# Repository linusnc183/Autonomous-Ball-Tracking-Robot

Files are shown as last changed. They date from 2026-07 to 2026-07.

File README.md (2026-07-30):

# Autonomous Ball Tracking Robot

A two-wheeled robot that visually tracks and follows a red ball. A Raspberry Pi handles vision (Picamera2 + OpenCV) and sends drive commands over UART to a custom STM32-based motor controller PCB, which closes the loop with encoder feedback and PID.

I designed the controller PCB from scratch in KiCad and wrote the embedded firmware in C (STM32CubeIDE, HAL).

**Skills demonstrated:** PCB design (KiCad) · embedded C / STM32 HAL · real-time control loops (PID) · analog/digital circuit design (power regulation, signal protection) · computer vision (OpenCV) · serial communication protocol design

https://github.com/user-attachments/assets/ed4e9871-f768-4ec5-b8f6-aebbd3194bc8

## Table of Contents

- [Features](#features)
- [System Architecture](#system-architecture)
- [Hardware](#hardware)
  - [Power](#power-powerkicad_sch)
  - [Motor Driver](#motor-driver-motordriverkicad_sch)
  - [Sensors](#sensors-sensorskicad_sch)
  - [MCU](#mcu-stm32kicad_sch)
  - [Raspberry Pi Interface](#raspberry-pi-interface-raspberrypikicad_sch)
  - [Debug](#debug-debugkicad_sch)
- [Firmware](#firmware-stm32-c--hal-stm32cubeide)
- [Vision](#vision-raspberry-pi-python)
- [Repository Structure](#repository-structure)
- [Getting Started](#getting-started)
- [Testing](#testing)
- [Future Improvements](#future-improvements)

## Features

- Real-time red-ball tracking with Picamera2 + OpenCV
- Custom 2-layer STM32G431 motor controller PCB with protection circuitry
- Closed-loop wheel velocity control via quadrature encoders + independent left/right PID
- UART link between Raspberry Pi and STM32, with a motor-safety timeout if the link drops
- Ultrasonic obstacle sensing (HC-SR04)

## System Architecture
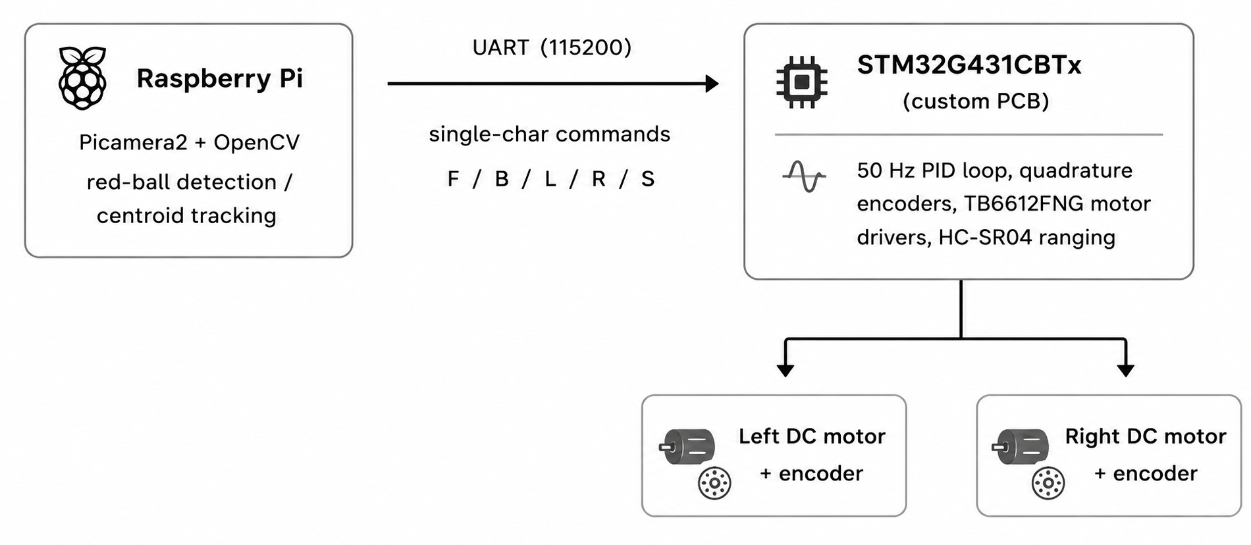
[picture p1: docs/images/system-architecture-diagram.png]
System architecture diagram


**Why split the work this way:** the Raspberry Pi handles the computationally heavy, non-deterministic side — image processing, ball detection, high-level navigation decisions. The STM32 handles the deterministic, real-time side — PWM generation, encoder feedback, PID control, and motor safety. Keeping them separate means a slow camera frame can never disturb the timing of the motor control loop.

## Hardware

Custom 2-layer controller PCB designed from scratch in KiCad 9 (schematic + layout), organized into hierarchical sheets by subsystem.

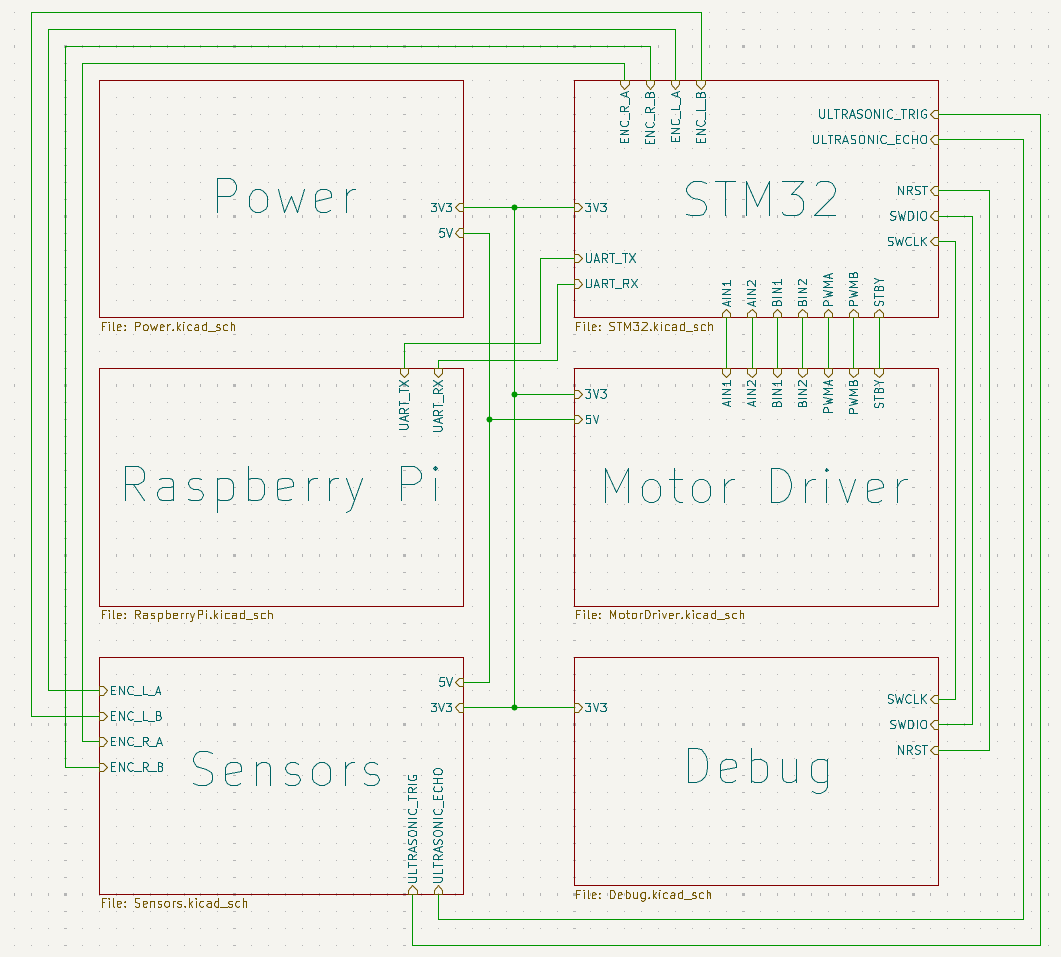
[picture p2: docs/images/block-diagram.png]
Block diagram


### Power (`Power.kicad_sch`)

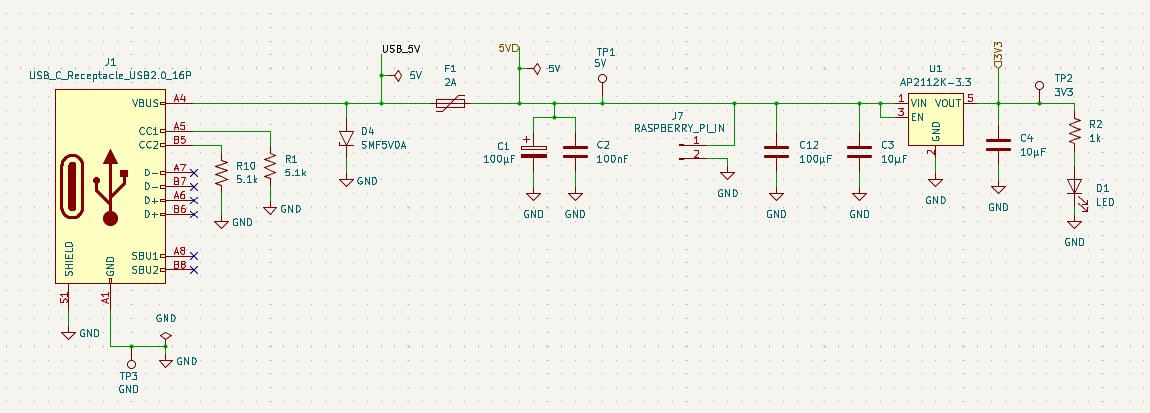
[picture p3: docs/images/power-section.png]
Power section


- **Input:** USB-C receptacle, with 5.1 kΩ pull-down resistors on the CC1/CC2 lines so the port correctly advertises itself to a USB-C source as a 5V/default-current sink.
- **Protection:** A resettable polyfuse (2A) guards the input against overcurrent/short circuits, and SMF5V0A TVS diodes clamp transient voltage spikes on the input.
- **Regulation:** An AP2112K-3.3 LDO steps the 5V USB rail down to 3.3V for the STM32 and logic-level signals, with bulk/decoupling caps (10 µF, 100 µF) on both rails.
- **Status indication:** Power-good LEDs on the 5V and 3.3V rails; test points (TP1–TP3) broken out for probing key rails during bring-up/debug.
- Both 5V and 3.3V are distributed to the Raspberry Pi header, so the Pi is powered directly from the board rather than needing its own separate supply.

### Motor Driver (`MotorDriver.kicad_sch`)

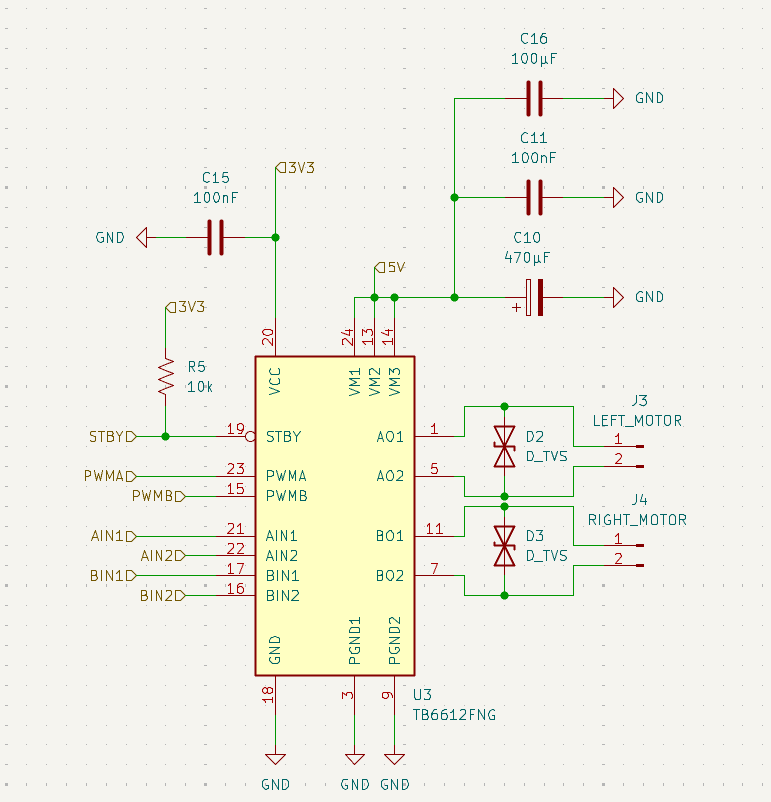
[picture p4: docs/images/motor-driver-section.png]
Motor driver section


- A single **TB6612FNG** dual H-bridge IC drives both DC motors (one chip, two independent channels — no need for two separate driver ICs).
- The STM32 drives `AIN1/AIN2`/`BIN1/BIN2` for direction and `PWMA`/`PWMB` (from TIM1 CH1/CH2) for speed, with `STBY` used to enable/disable the driver in firmware.
- Bulk capacitance (470 µF + 100 µF) sits close to the motor supply input to absorb the current spikes motors draw on startup/direction changes.
- TVS diodes across the motor connector outputs suppress the inductive kickback/flyback transients DC motors generate when switching direction.

### Sensors (`Sensors.kicad_sch`)

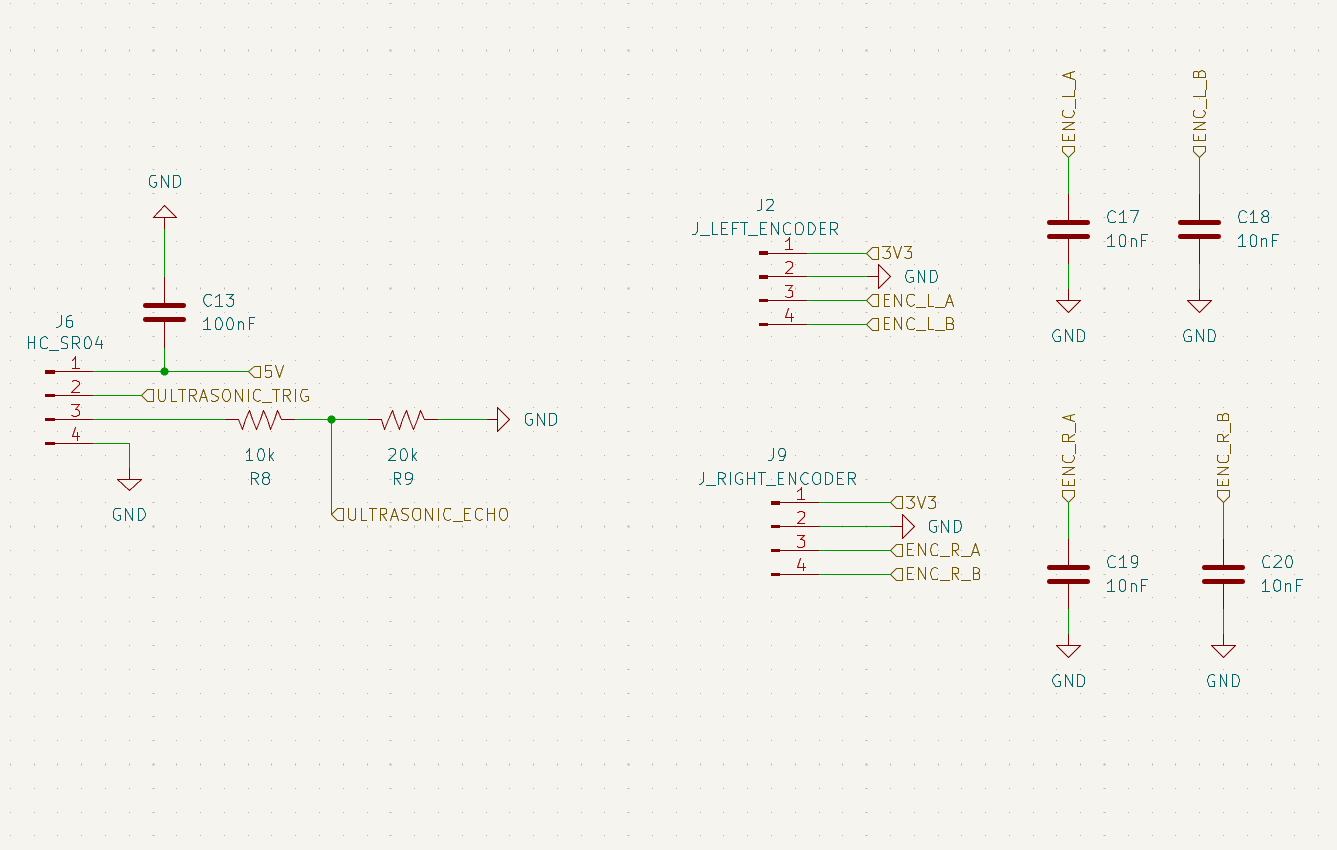
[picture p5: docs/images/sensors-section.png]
Sensors section


- **HC-SR04 ultrasonic:** `TRIG`/`ECHO` connect directly to the STM32 (PA0/PA1). Since the HC-SR04's echo pin outputs a 5V logic level and the STM32 is 3.3V-tolerant, a resistive divider (20 kΩ/10 kΩ) steps the echo signal down to a safe ~3.3V before it reaches the MCU pin.
- **Quadrature encoders:** Separate 4-pin headers for the left and right motor encoders, each feeding an A/B channel pair into the STM32's hardware timer encoder inputs (TIM3 for one wheel, TIM4 for the other).
- Small filtering capacitors (10 nF) on the encoder/sensor lines help reject electrical noise from the nearby motors.

### MCU (`STM32.kicad_sch`)

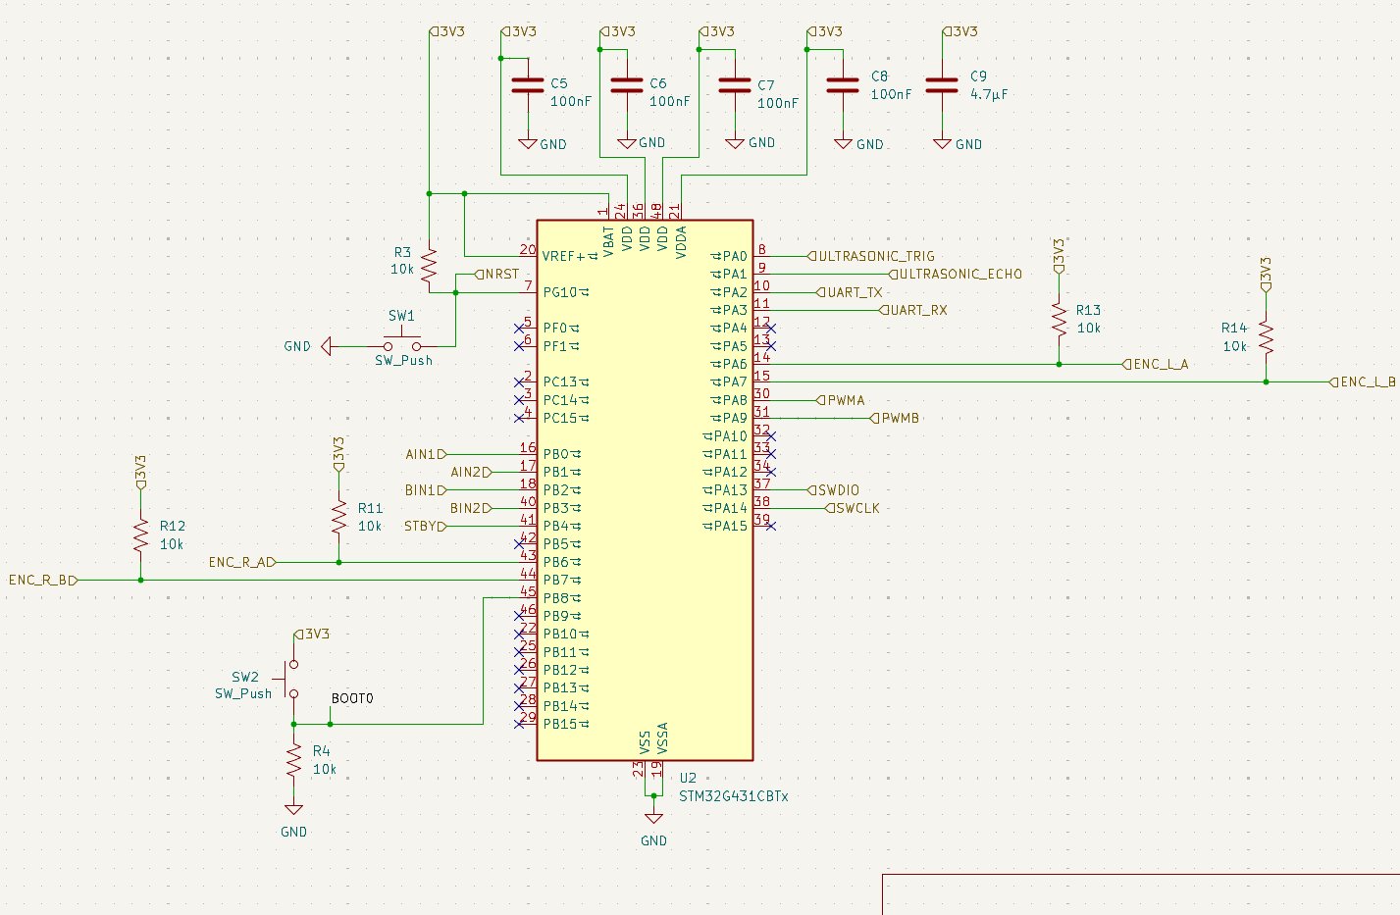
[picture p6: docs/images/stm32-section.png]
STM32 section


- STM32G431CBTx (Arm Cortex-M4, 170 MHz), with standard decoupling capacitors on all supply pins plus a bulk 4.7 µF cap.
- BOOT0 and NRST have pull resistors for reliable reset/boot behavior; two push buttons (SW1/SW2) are broken out for reset and boot-mode selection during flashing/debug.

### Raspberry Pi Interface (`RaspberryPi.kicad_sch`)

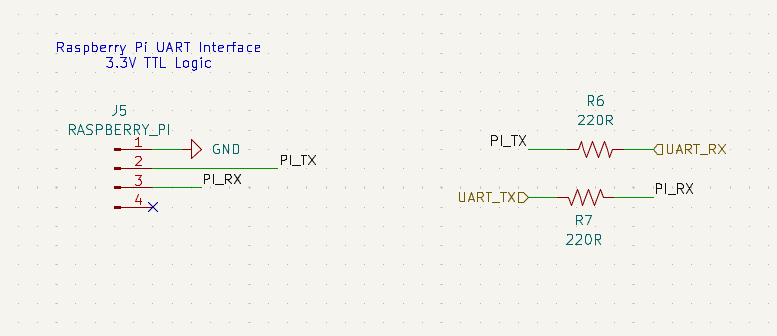
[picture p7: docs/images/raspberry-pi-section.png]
Raspberry Pi section


- A 4-pin header carries 5V, 3.3V, and UART TX/RX between the board and the Raspberry Pi's GPIO header.
- Series resistors (220 Ω) on the UART lines add a layer of protection against miswiring/contention; no level shifting is needed since both the STM32 and Pi run 3.3V logic.

### Debug (`Debug.kicad_sch`)

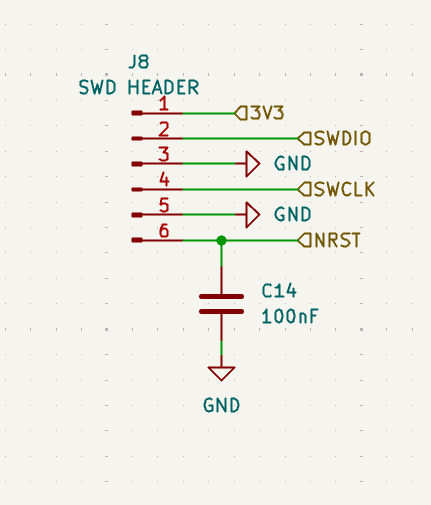
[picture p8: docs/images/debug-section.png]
Debug section


- 6-pin SWD header (SWDIO, SWCLK, NRST, 3V3, GND) for programming and debugging the STM32 with an ST-Link, independent of the USART2 link to the Pi.

**Key parts:** STM32G431CBTx · TB6612FNG motor driver · HC-SR04 ultrasonic sensor · 2x quadrature encoders · AP2112K-3.3 LDO · USB-C power input · SMF5V0A TVS protection

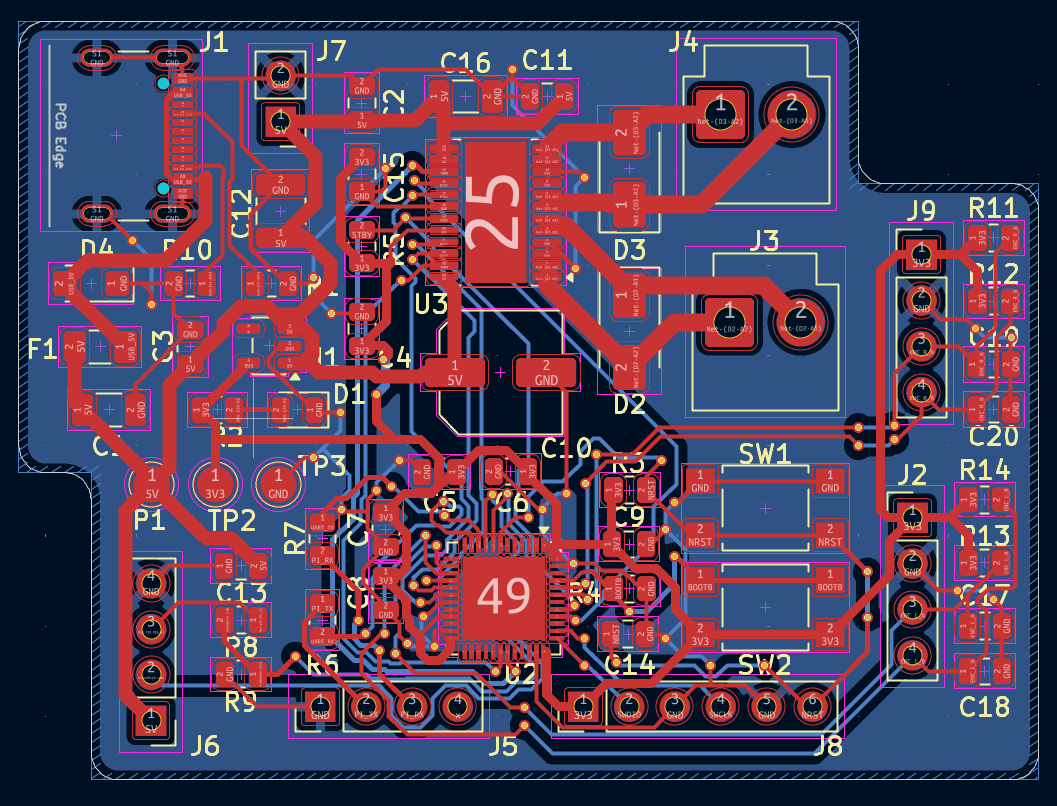
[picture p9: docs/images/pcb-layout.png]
PCB layout

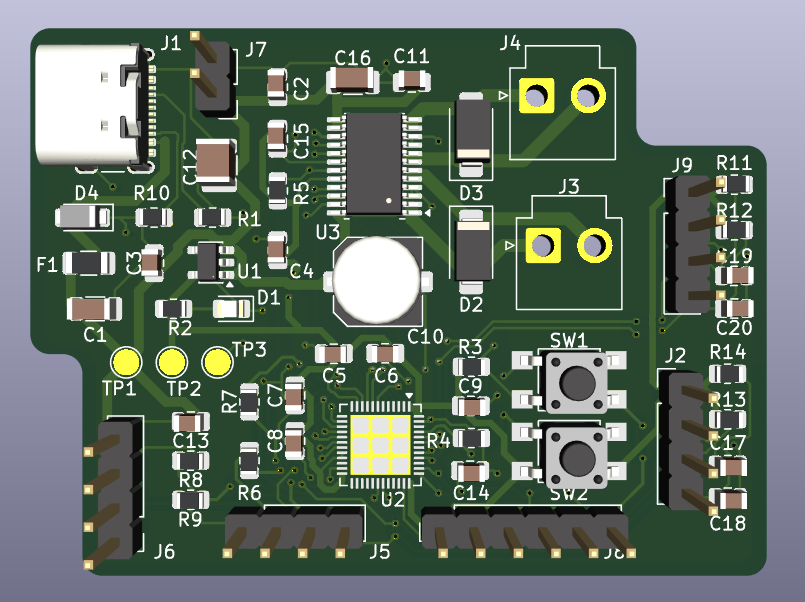
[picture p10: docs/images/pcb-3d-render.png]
PCB 3D render


## Firmware (STM32, C / HAL, STM32CubeIDE)

| Module | Responsibility |
|---|---|
| `main.c` | System init, 50 Hz control loop scheduling, 10 Hz ultrasonic scheduling |
| `motor.c/h` | PWM + direction output to the TB6612FNG (TIM1 CH1/CH2, AIN/BIN GPIO) |
| `encoder.c/h` | Reads TIM3/TIM4 in quadrature (TI12) encoder mode, converts counts to counts/sec |
| `pid.c/h` | Per-wheel velocity PID with conditional-integration anti-windup |
| `uart_control.c/h` | Parses single-character drive commands from the Pi over USART2 (interrupt-driven) |
| `ultrasonic.c/h` | Software-timed HC-SR04 ranging using the DWT cycle counter for microsecond resolution |

### Control loop

- Runs at 50 Hz (`CONTROL_LOOP_PERIOD_MS = 20`): reads both encoders, runs independent PID controllers for the left/right wheel, and writes the resulting PWM + direction to the motor driver.
- Ultrasonic sensing runs on its own 10 Hz cadence, separate from the control loop, since an HC-SR04 read is a blocking, up-to-30 ms operation and would otherwise disturb the PID's timing.

### PID with anti-windup

Each wheel has an independent PID controller operating on measured wheel speed (encoder counts/sec) with output clamped to a ±1000 PWM range. Integral accumulation uses **conditional integration**: once the output saturates, the integral term stops accumulating unless the error is already pulling it back out of saturation. This prevents the classic windup overshoot where a saturated integrator keeps growing while the motor is already maxed out.

### Quadrature encoding

Wheel encoders are read using the STM32's hardware timer encoder mode (`TIM_ENCODERMODE_TI12`) on TIM3/TIM4, decoding both edges of both channels for full 4x quadrature resolution and reliable direction sensing, rather than software-polling the encoder pins.

### UART command protocol + failsafe

The Pi sends single-byte commands over USART2 (interrupt-driven RX):

| Command | Action |
|---|---|
| `F` | Forward |
| `B` | Backward |
| `L` | Turn left |
| `R` | Turn right |
| `S` | Stop |

If no byte arrives for 500 ms (e.g. the Pi crashes or the link drops), the firmware automatically zeroes both wheel targets and stops the robot — the robot doesn't require a "stop" command to fail safe.

### Ultrasonic ranging without a timer channel

The HC-SR04's echo line isn't wired to a timer input-capture pin, so pulse width is timed in software using the Cortex-M4's DWT cycle counter, giving microsecond-level resolution independent of the main loop's timing.

## Vision (Raspberry Pi, Python)

`ball_tracking.py` captures frames with Picamera2, finds the ball with OpenCV, and streams drive commands to the STM32 over the same UART protocol the firmware implements.

**Detection:** Frames are converted to HSV and thresholded for red across two hue ranges (red wraps around hue 0/180 in OpenCV's HSV space), combined into one mask, then cleaned up with erosion/dilation to remove noise. The largest contour's minimum enclosing circle gives the ball's center and apparent radius.

**Decision logic:** The ball's horizontal offset from frame-center picks a turn command first (turning takes priority so the robot centers on the ball before closing distance); once centered, the ball's apparent radius acts as a distance proxy — small radius drives forward, large radius backs up, and an in-between radius holds position.

**Serial keepalive thread:** The STM32 firmware stops the motors if it doesn't receive a UART byte within 500 ms. Rather than tying that timing to the camera's frame rate, `SerialCommander` runs a dedicated background thread that resends the current command every 150 ms on its own schedule — so a slow or dropped camera frame can never cause an unexpected stop or leave a stale command running longer than intended.

**Debounced ball loss:** Losing the ball for a single frame doesn't stop the robot; it keeps issuing the last command until the ball has been missing for a full second, avoiding jerky stops from momentary detection blips.

Run it with:
```bash
pip install picamera2 opencv-python pyserial numpy
python3 ball_tracking.py
```
Requires UART enabled via `raspi-config` (Interface Options → Serial Port) and, on Pi models where UART is routed through Bluetooth, `dtoverlay=disable-bt` in `/boot/firmware/config.txt`. Wiring: Pi GPIO14 (TX) → STM32 PA3 (RX), Pi GPIO15 (RX) → STM32 PA2 (TX), common ground — both sides are 3.3V logic, no level shifter needed.

## Repository Structure

```
Ball_Tracking_Robot/
├── README.md
├── .gitignore
│
├── hardware/                          # Custom PCB design files
│   └── PCB/
│       ├── KiCad/
│       │   ├── Ball_Tracking_Robot_Controller.kicad_pro
│       │   ├── Ball_Tracking_Robot_Controller.kicad_sch
│       │   ├── Ball_Tracking_Robot_Controller.kicad_pcb
│       │   ├── STM32.kicad_sch
│       │   ├── Power.kicad_sch
│       │   ├── MotorDriver.kicad_sch
│       │   ├── Sensors.kicad_sch
│       │   ├── RaspberryPi.kicad_sch
│       │   └── Debug.kicad_sch
│       ├── Gerbers/                   # Manufacturing files
│       └── BOM/
│
├── firmware/                          # STM32 embedded firmware (STM32CubeIDE project)
│   └── STM32CubeIDE/
│       ├── Core/
│       │   ├── Inc/                   # main.h, motor.h, encoder.h, pid.h,
│       │   │                          # uart_control.h, ultrasonic.h, ...
│       │   └── Src/                   # main.c, motor.c, encoder.c, pid.c,
│       │                              # uart_control.c, ultrasonic.c, ...
│       ├── Drivers/                   # CMSIS + STM32G4xx HAL
│       └── STM32CubeMX/
│           └── Ball_Tracking_Robot.ioc
│
├── software/                          # Raspberry Pi vision code
│   └── RaspberryPi/
│       └── ball_tracking.py
│
├── tests/                             # Hardware/firmware/vision validation
│   ├── uart_test/
│   ├── encoder_test/
│   └── motor_test/
│
└── docs/
    └── images/                        # Schematic screenshots, PCB renders
```

## Getting Started

### Hardware
1. Open `hardware/PCB/KiCad/Ball_Tracking_Robot_Controller.kicad_pro` in [KiCad 9](https://www.kicad.org/).
2. Review the schematics/PCB layout, then generate Gerbers/BOM for fabrication and assembly.

### Firmware
1. Open `firmware/STM32CubeIDE` directly as a project in STM32CubeIDE (targets the STM32G431CBTx).
2. Flash over the onboard SWD header with an ST-Link.
3. Connect USART2 (PA2/PA3) to the Raspberry Pi's UART pins.

### Vision
1. On the Raspberry Pi, install dependencies and run `software/RaspberryPi/ball_tracking.py` (see the [Vision](#vision-raspberry-pi-python) section above for setup details).

## Testing

Validation performed during hardware/firmware bring-up:

- **Hardware:** 3.3V/5V rail verification, UART loopback test, motor driver output check, encoder direction/count check, ultrasonic ranging accuracy check
- **Firmware:** PID step-response tuning, encoder speed measurement validation, UART-disconnect failsafe test (confirms motors stop within 500 ms of link loss)
- **Vision:** red-ball detection under varying lighting conditions, ball-loss/recovery behavior, end-to-end command latency

## Future Improvements

- Replace single-character UART commands with a packet-based protocol (with CRC error checking)
- Add an IMU for orientation estimation
- Add wheel odometry and localization
- Move from manual PID tuning toward autonomous/self-tuning gains
- Full autonomous navigation (beyond ball-following)

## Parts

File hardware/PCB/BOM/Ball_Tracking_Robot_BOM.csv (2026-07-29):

Reference | Qty | Value | DNP | Exclude from BOM | Exclude from Board | Footprint | Datasheet
C1,C16 | 2 | 100μF |  |  |  | Capacitor_SMD:C_1206_3216Metric | ~
C2,C5,C6,C7,C8,C11,C13,C14,C15 | 9 | 100nF |  |  |  | Capacitor_SMD:C_0805_2012Metric | ~
C3,C4 | 2 | 10μF |  |  |  | Capacitor_SMD:C_0805_2012Metric | ~
C9 | 1 | 4.7μF |  |  |  | Capacitor_SMD:C_0805_2012Metric | ~
C10 | 1 | 470μF |  |  |  | Capacitor_SMD:C_Elec_6.3x5.8 | ~
C12 | 1 | 100μF |  |  |  | Capacitor_SMD:C_1210_3225Metric | ~
C17,C18,C19,C20 | 4 | 10nF |  |  |  | Capacitor_SMD:C_0805_2012Metric | ~
D1 | 1 | LED |  |  |  | LED_SMD:LED_0805_2012Metric | ~
D2,D3 | 2 | D_TVS |  |  |  | Diode_SMD:D_SMA | ~
D4 | 1 | SMF5V0A |  |  |  | Diode_SMD:D_SMF | https://www.vishay.com/doc?85881
F1 | 1 | 2A |  |  |  | Fuse:Fuse_1206_3216Metric | ~
J1 | 1 | USB_C_Receptacle_USB2.0_16P |  |  |  | Connector_USB:USB_C_Receptacle_GCT_USB4105-xx-A_16P_TopMnt_Horizontal | https://www.usb.org/sites/default/files/documents/usb_type-c.zip
J2 | 1 | J_LEFT_ENCODER |  |  |  | Connector_PinHeader_2.54mm:PinHeader_1x04_P2.54mm_Vertical | ~
J3 | 1 | LEFT_MOTOR |  |  |  | Connector_JST:JST_VH_B2P-VH_1x02_P3.96mm_Vertical | ~
J4 | 1 | RIGHT_MOTOR |  |  |  | Connector_JST:JST_VH_B2P-VH_1x02_P3.96mm_Vertical | ~
J5 | 1 | RASPBERRY_PI |  |  |  | Connector_PinHeader_2.54mm:PinHeader_1x04_P2.54mm_Vertical | ~
J6 | 1 | HC_SR04 |  |  |  | Connector_PinHeader_2.54mm:PinHeader_1x04_P2.54mm_Vertical | ~
J7 | 1 | RASPBERRY_PI_IN |  |  |  | Connector_PinHeader_2.54mm:PinHeader_1x02_P2.54mm_Vertical | ~
J8 | 1 | SWD HEADER |  |  |  | Connector_PinHeader_2.54mm:PinHeader_1x06_P2.54mm_Vertical | ~
J9 | 1 | J_RIGHT_ENCODER |  |  |  | Connector_PinHeader_2.54mm:PinHeader_1x04_P2.54mm_Vertical | ~
R1,R10 | 2 | 5.1k |  |  |  | Resistor_SMD:R_0805_2012Metric | ~
R2 | 1 | 1k |  |  |  | Resistor_SMD:R_0805_2012Metric | ~
R3,R4,R5,R8,R11,R12,R13,R14 | 8 | 10k |  |  |  | Resistor_SMD:R_0805_2012Metric | ~
R6,R7 | 2 | 220R |  |  |  | Resistor_SMD:R_0805_2012Metric | ~
R9 | 1 | 20k |  |  |  | Resistor_SMD:R_0805_2012Metric | ~
SW1,SW2 | 2 | SW_Push |  |  |  | Button_Switch_SMD:SW_SPST_TL3305A | ~
TP1 | 1 | 5V |  |  |  | TestPoint:TestPoint_Pad_D2.0mm | ~
TP2 | 1 | 3V3 |  |  |  | TestPoint:TestPoint_Pad_D2.0mm | ~
TP3 | 1 | GND |  |  |  | TestPoint:TestPoint_Pad_D2.0mm | ~
U1 | 1 | AP2112K-3.3 |  |  |  | Package_TO_SOT_SMD:SOT-23-5 | https://www.diodes.com/assets/Datasheets/AP2112.pdf
U2 | 1 | STM32G431CBTx |  |  |  | Package_DFN_QFN:QFN-48-1EP_6x6mm_P0.4mm_EP4.6x4.6mm | https://www.st.com/resource/en/datasheet/stm32g431cb.pdf
U3 | 1 | TB6612FNG |  |  |  | Package_SO:HTSSOP-24-1EP_4.4x7.8mm_P0.65mm_EP3.4x7.8mm_Mask2.4x4.68mm | https://toshiba.semicon-storage.com/us/product/linear/motordriver/detail.TB6612FNG.html

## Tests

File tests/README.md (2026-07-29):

# Hardware Tests

This directory contains validation tests for the Ball Tracking Robot system.

The purpose of these tests is to verify individual hardware and firmware subsystems before full system integration.

---

# Test Structure

```
tests/
│
├── uart_test/
│   └── uart_test.py
│
├── motor_test/
│   └── motor_test.c
│
├── encoder_test/
│   └── encoder_test.c
│
└── pid_test/
    └── pid_test.py
```

---

# UART Communication Test

## Location

```
uart_test/uart_test.py
```

## Purpose

Verifies communication between:

- Raspberry Pi
- STM32 motor controller

Tests:

- UART wiring
- Baud rate configuration
- Command transmission
- STM32 command reception

## Hardware Required

- Raspberry Pi
- STM32 controller PCB
- UART connection

## Run

```bash
python3 uart_test.py
```

## Expected Behavior

The terminal will allow manual movement commands:

| Command | Function |
|---|---|
| F | Forward |
| B | Backward |
| L | Turn Left |
| R | Turn Right |
| S | Stop |

The robot should respond to each command.

---

# Motor Driver Test

## Location

```
motor_test/motor_test.c
```

## Purpose

Verifies the TB6612FNG motor driver interface.

Tests:

- Motor enable control
- PWM output
- Direction pins
- Left motor operation
- Right motor operation

## Hardware Required

- STM32 controller PCB
- TB6612FNG motor driver
- Motors connected

## Expected Behavior

The motors should:

1. Move forward
2. Stop
3. Move backward
4. Stop

This confirms:

- PWM signals are generated correctly
- Motor direction pins are correct
- Motor driver wiring is functional

---

# Encoder Test

## Location

```
encoder_test/encoder_test.c
```

## Purpose

Verifies wheel encoder operation.

Tests:

- Encoder power
- A/B channel wiring
- Timer encoder mode configuration
- Counting direction
- Wheel feedback

## Hardware Required

- STM32 controller PCB
- Quadrature wheel encoders

## Expected Behavior

UART output should display changing encoder counts:

```
Left: 120   Right: 118

Left: 240   Right: 236
```

When wheels rotate forward:

```
Encoder counts increase
```

When wheels rotate backward:

```
Encoder counts decrease
```

---

# PID Control Test

## Location

```
pid_test/pid_test.py
```

## Purpose

Tests motor PID control behavior before connecting the physical robot.

The simulation verifies:

- Error calculation
- Proportional response
- Integral response
- Derivative response
- System settling behavior

## Expected Behavior

The simulated motor speed should:

- Increase toward the target speed
- Reduce error over time
- Stabilize near the desired value

Example:

```
Target Speed: 100 RPM

Time     Speed
0s       0 RPM
1s       65 RPM
2s       92 RPM
3s       99 RPM
4s       100 RPM
```

---

# Test Procedure

Subsystem testing should be completed in this order:

## 1. Power Validation

Verify:

- 5V rail
- 3.3V rail
- No excessive current draw

---

## 2. UART Test

Verify:

- Raspberry Pi communication
- STM32 command reception

---

## 3. Motor Test

Verify:

- Motor direction
- PWM control
- TB6612FNG operation

---

## 4. Encoder Test

Verify:

- Encoder counts
- Direction detection
- Timer configuration

---

## 5. PID Test

Verify:

- Closed-loop speed control
- Stable motor response

---

# Future Tests

Additional validation tests planned:

- Battery voltage monitoring
- Current consumption measurement
- Ultrasonic sensor validation
- Camera tracking latency testing
- Full autonomous navigation testing
- Long-duration reliability testing

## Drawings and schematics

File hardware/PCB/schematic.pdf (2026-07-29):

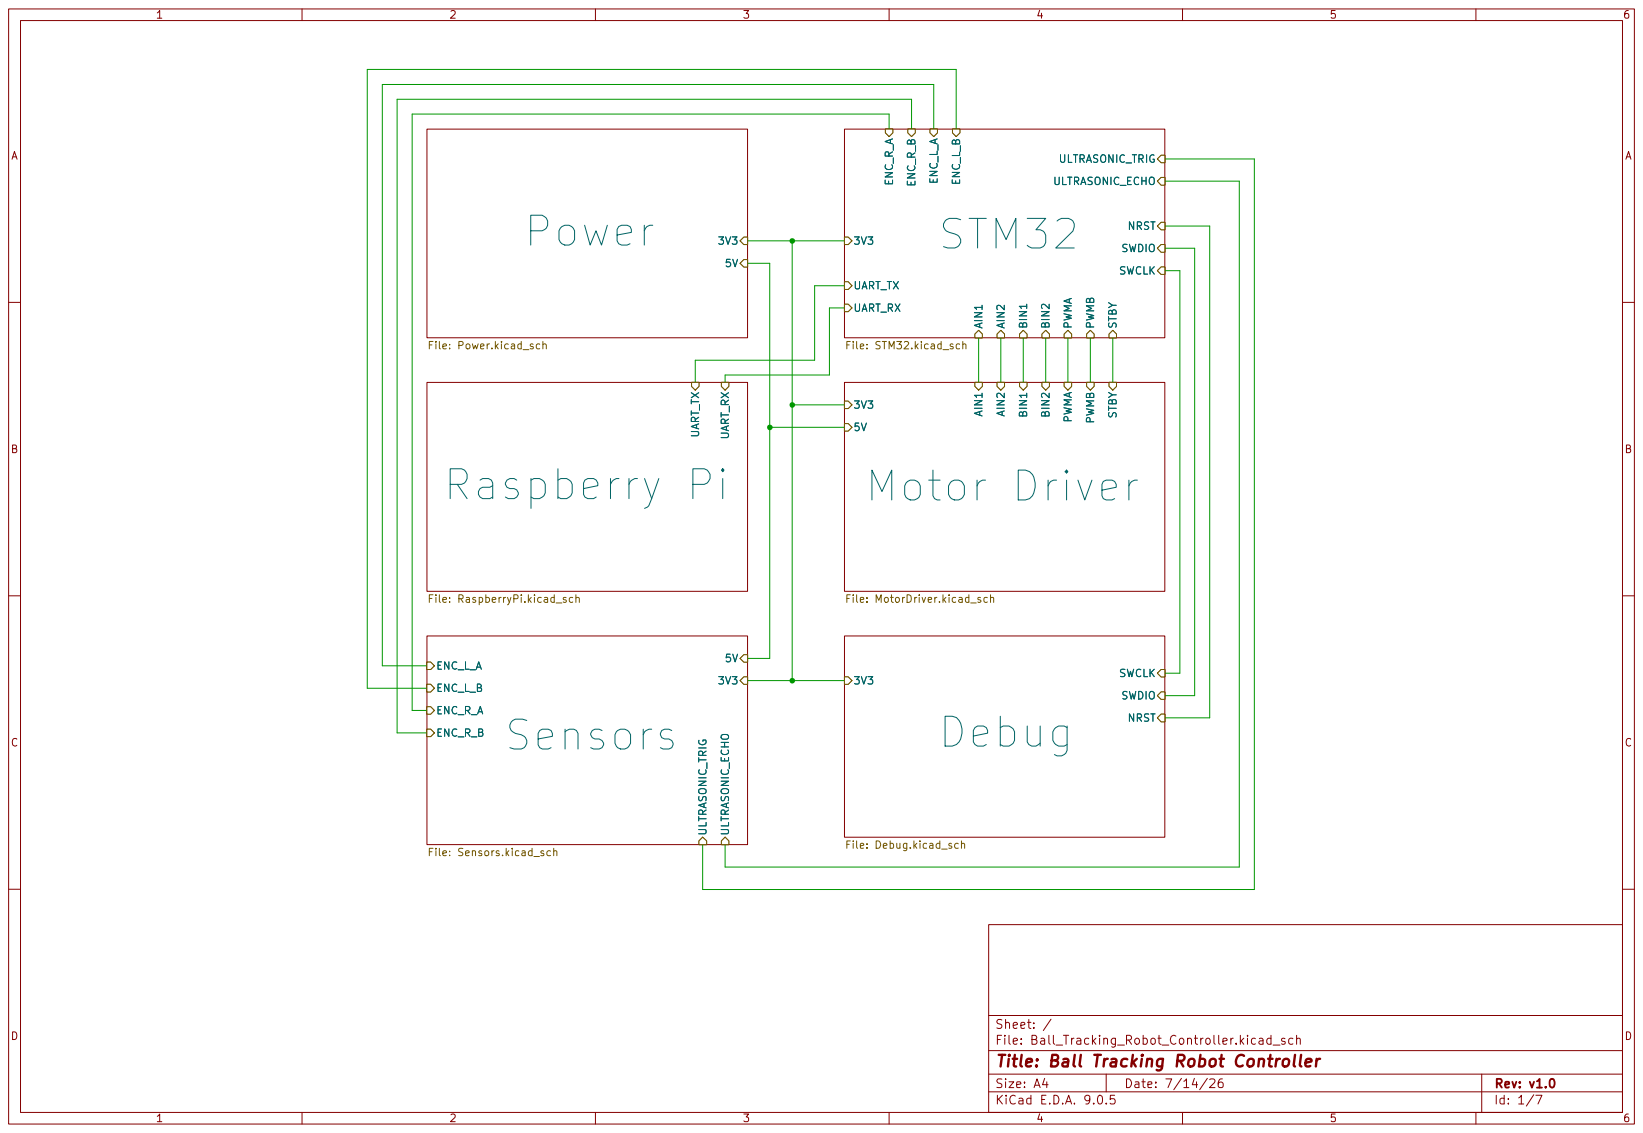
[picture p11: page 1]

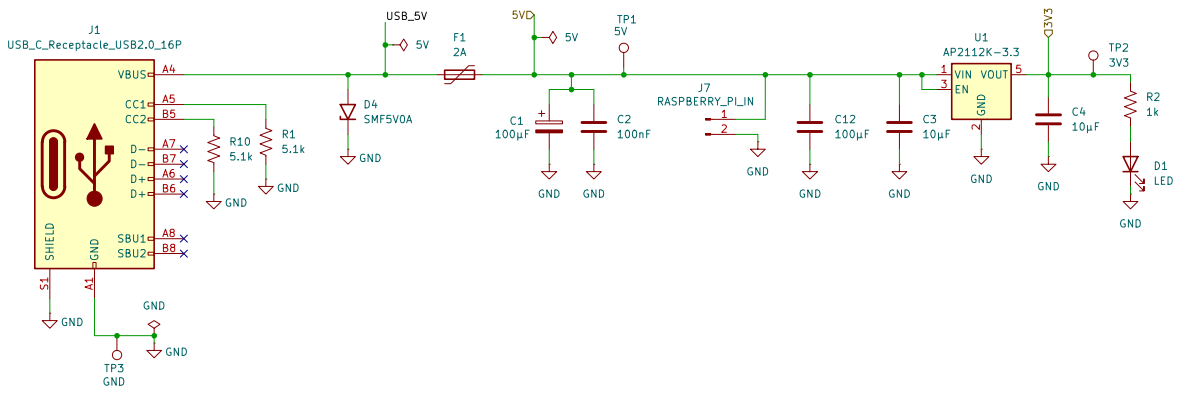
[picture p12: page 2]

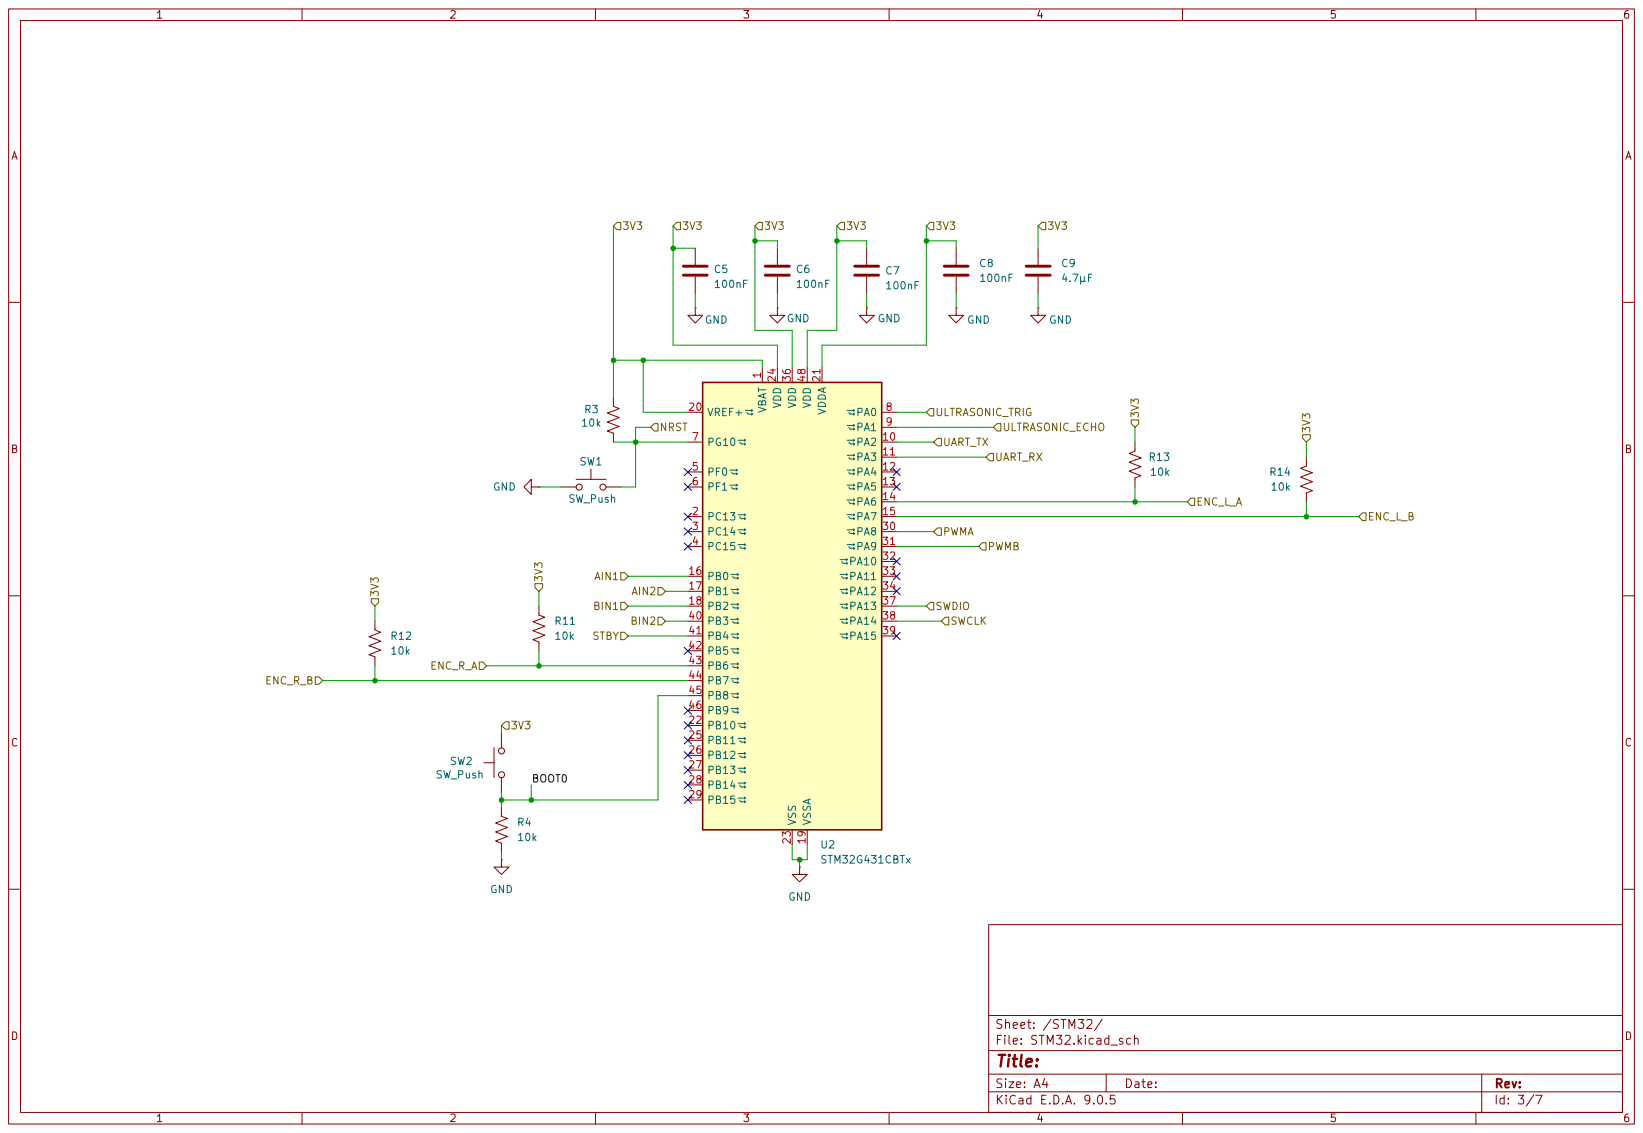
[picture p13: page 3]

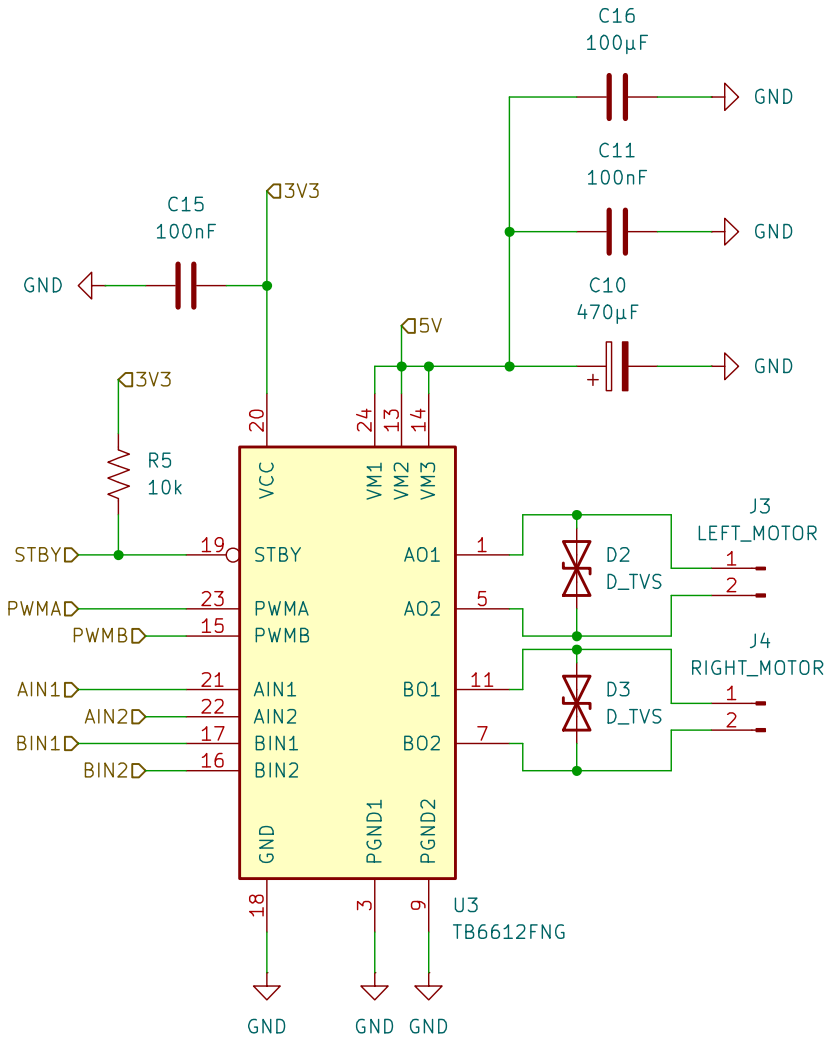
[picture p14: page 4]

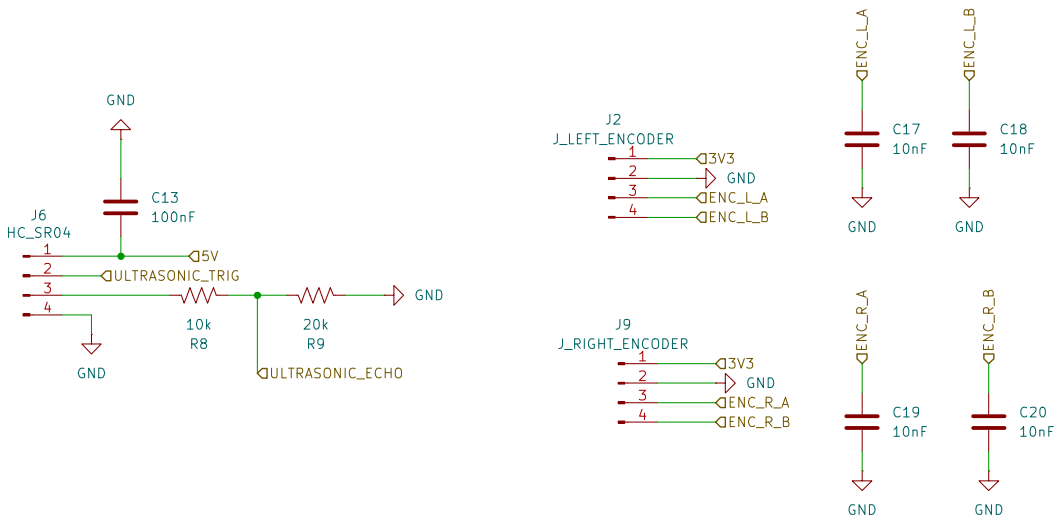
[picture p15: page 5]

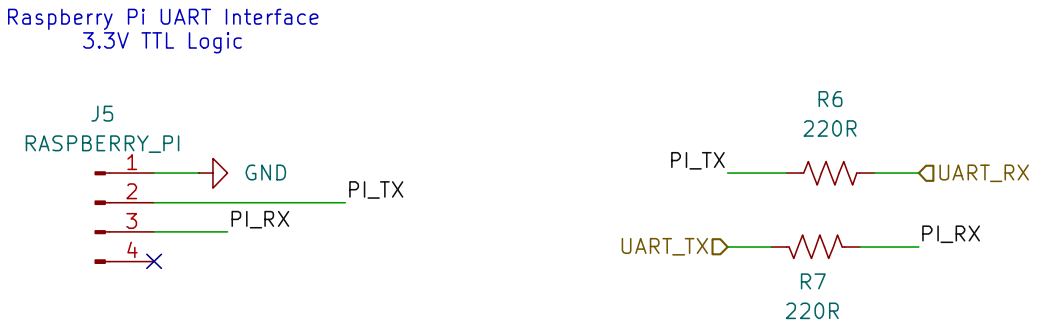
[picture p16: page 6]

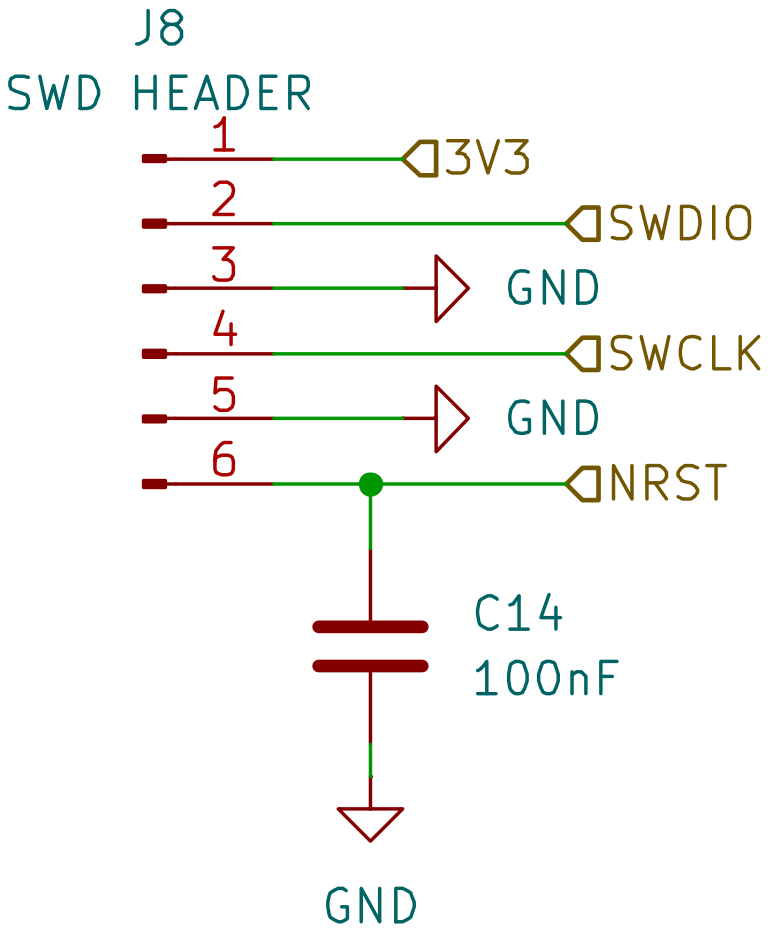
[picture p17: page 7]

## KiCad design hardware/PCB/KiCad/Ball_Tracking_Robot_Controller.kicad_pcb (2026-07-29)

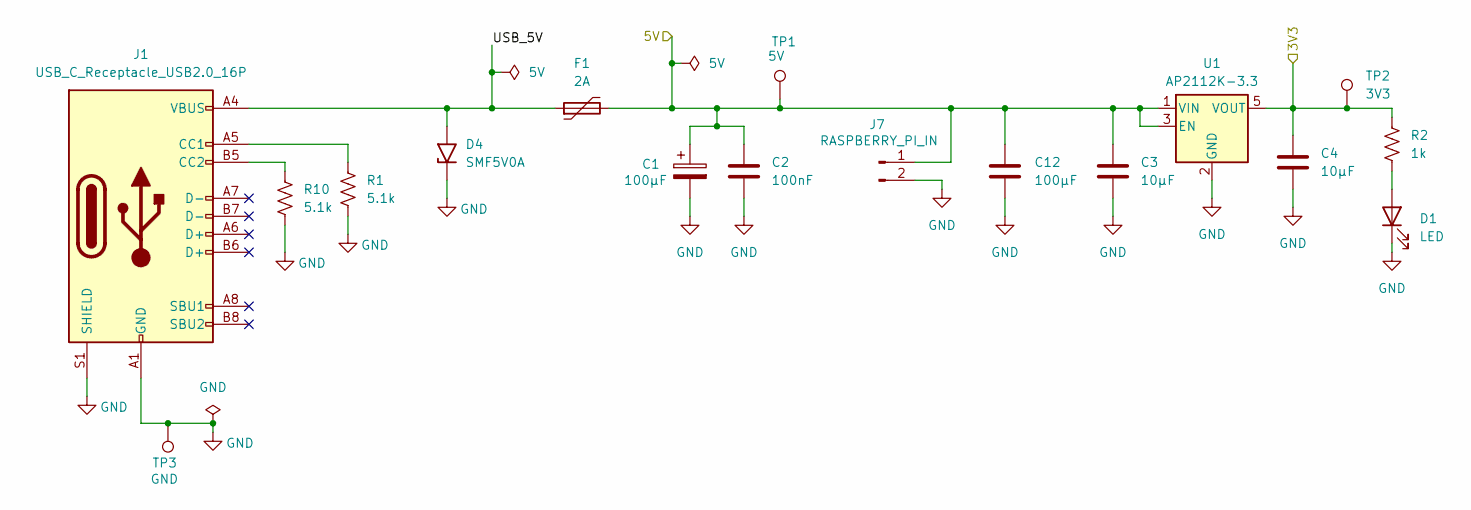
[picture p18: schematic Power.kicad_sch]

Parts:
C1: 100μF; C_1206_3216Metric
C2: 100nF; C_0805_2012Metric
C3, C4: 10μF; C_0805_2012Metric
C12: 100μF; C_1210_3225Metric
D1: LED; LED_0805_2012Metric
D4: SMF5V0A; D_SMF
F1: 2A; Fuse_1206_3216Metric
J1: USB_C_Receptacle_USB2.0_16P; USB_C_Receptacle_GCT_USB4105-xx-A_16P_TopMnt_Horizontal
J7: RASPBERRY_PI_IN; PinHeader_1x02_P2.54mm_Vertical
R1, R10: 5.1k; R_0805_2012Metric
R2: 1k; R_0805_2012Metric
TP1: 5V; TestPoint_Pad_D2.0mm
TP2: 3V3; TestPoint_Pad_D2.0mm
TP3: GND; TestPoint_Pad_D2.0mm
U1: AP2112K-3.3; SOT-23-5

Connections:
/Debug/3V3: C4.1, R2.1, TP2.1, U1.5 (VOUT); also elsewhere on the board
/Motor Driver/5V: C1.1, C2.1, C3.1, C12.1, F1.2, J7.1, TP1.1, U1.1 (VIN), U1.3 (EN); also elsewhere on the board
/Power/USB_5V: D4.2 (A2), F1.1, J1.A4 (VBUS), J1.A9 (VBUS), J1.B4 (VBUS), J1.B9 (VBUS)
GND: C1.2, C2.2, C3.2, C4.2, C12.2, D1.1 (K), D4.1 (A1), J1.A1 (GND), J1.A12 (GND), J1.B1 (GND), J1.B12 (GND), J1.S1 (SHIELD), J7.2, R1.2, R10.2, TP3.1, U1.2 (GND); also elsewhere on the board
unnamed: D1.2 (A), R2.2
unnamed: J1.A5 (CC1), R1.1
unnamed: J1.B5 (CC2), R10.1

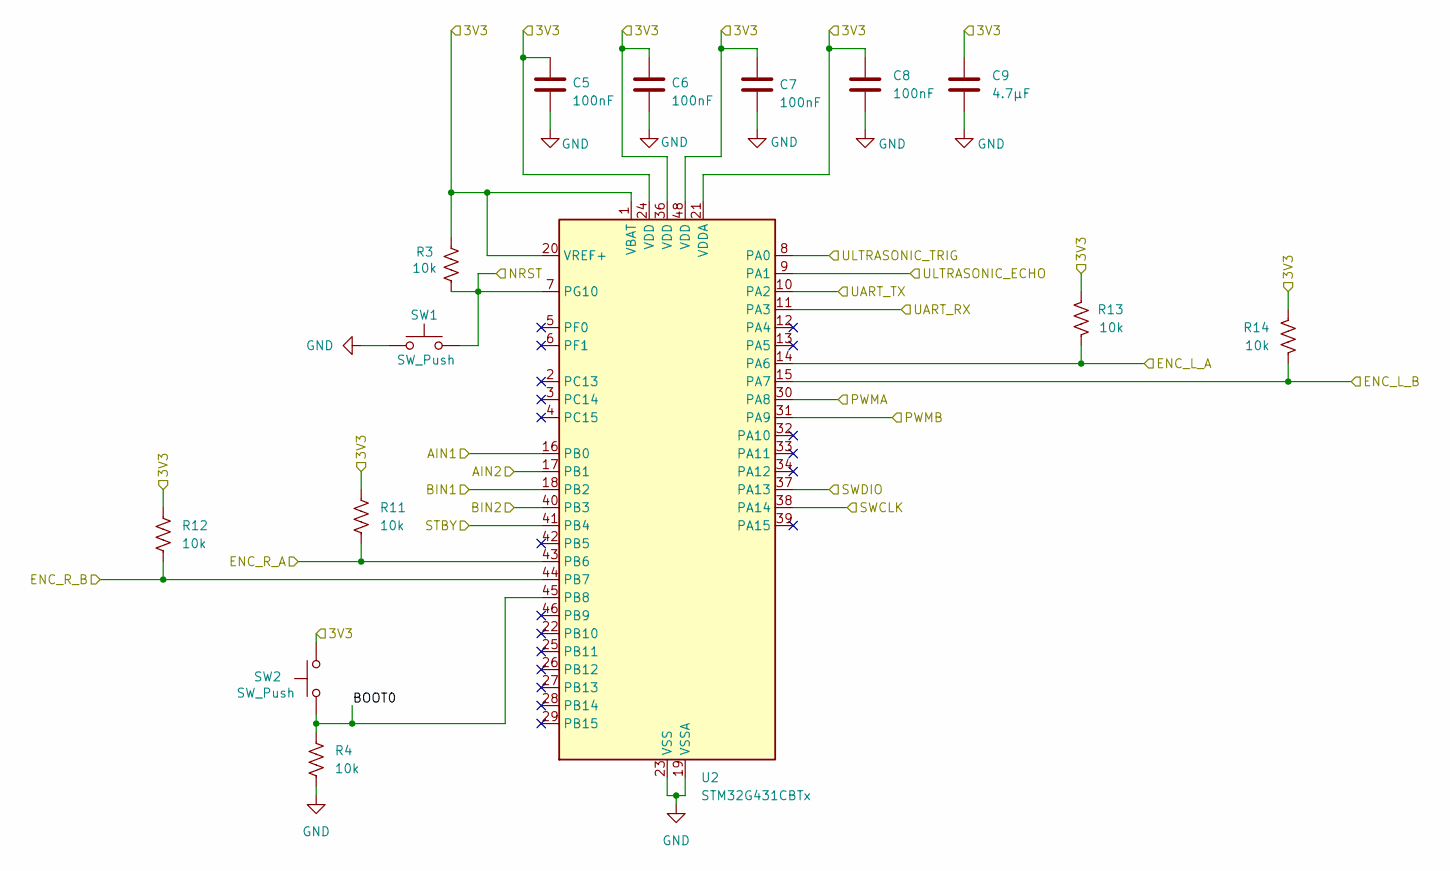
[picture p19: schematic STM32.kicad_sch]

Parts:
C5, C6, C7, C8: 100nF; C_0805_2012Metric
C9: 4.7μF; C_0805_2012Metric
R3, R4, R11, R12, R13, R14: 10k; R_0805_2012Metric
SW1, SW2: SW_Push; SW_SPST_TL3305A
U2: STM32G431CBTx; QFN-48-1EP_6x6mm_P0.4mm_EP4.6x4.6mm

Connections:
/Debug/3V3: C5.1, C6.1, C7.1, C8.1, C9.1, R3.1, R11.1, R12.1, R13.1, R14.1, SW2.2, U2.1 (VBAT), U2.20 (VREF+), U2.21 (VDDA), U2.24 (VDD), U2.36 (VDD), U2.48 (VDD); also elsewhere on the board
/Debug/NRST: R3.2, SW1.2, U2.7 (PG10); also elsewhere on the board
/Debug/SWCLK: U2.38 (PA14); also elsewhere on the board
/Debug/SWDIO: U2.37 (PA13); also elsewhere on the board
/Motor Driver/AIN1: U2.16 (PB0); also elsewhere on the board
/Motor Driver/AIN2: U2.17 (PB1); also elsewhere on the board
/Motor Driver/BIN1: U2.18 (PB2); also elsewhere on the board
/Motor Driver/BIN2: U2.40 (PB3); also elsewhere on the board
/Motor Driver/PWMA: U2.30 (PA8); also elsewhere on the board
/Motor Driver/PWMB: U2.31 (PA9); also elsewhere on the board
/Motor Driver/STBY: U2.41 (PB4); also elsewhere on the board
/Raspberry Pi/UART_RX: U2.11 (PA3); also elsewhere on the board
/Raspberry Pi/UART_TX: U2.10 (PA2); also elsewhere on the board
/STM32/BOOT0: R4.1, SW2.1, U2.45 (PB8)
/STM32/ENC_L_A: R13.2, U2.14 (PA6); also elsewhere on the board
/STM32/ENC_L_B: R14.2, U2.15 (PA7); also elsewhere on the board
/STM32/ENC_R_A: R11.2, U2.43 (PB6); also elsewhere on the board
/STM32/ENC_R_B: R12.2, U2.44 (PB7); also elsewhere on the board
/STM32/ULTRASONIC_ECHO: U2.9 (PA1); also elsewhere on the board
/STM32/ULTRASONIC_TRIG: U2.8 (PA0); also elsewhere on the board
GND: C5.2, C6.2, C7.2, C8.2, C9.2, R4.2, SW1.1, U2.19 (VSSA), U2.23 (VSS), U2.35 (VSS), U2.47 (VSS); also elsewhere on the board

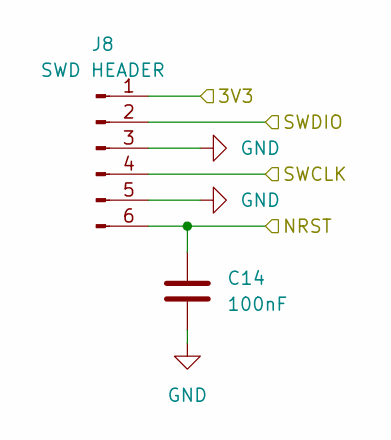
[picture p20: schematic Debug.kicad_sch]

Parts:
C14: 100nF; C_0805_2012Metric
J8: SWD HEADER; PinHeader_1x06_P2.54mm_Vertical

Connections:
/Debug/3V3: J8.1; also elsewhere on the board
/Debug/NRST: C14.1, J8.6; also elsewhere on the board
/Debug/SWCLK: J8.4; also elsewhere on the board
/Debug/SWDIO: J8.2; also elsewhere on the board
GND: C14.2, J8.3, J8.5; also elsewhere on the board

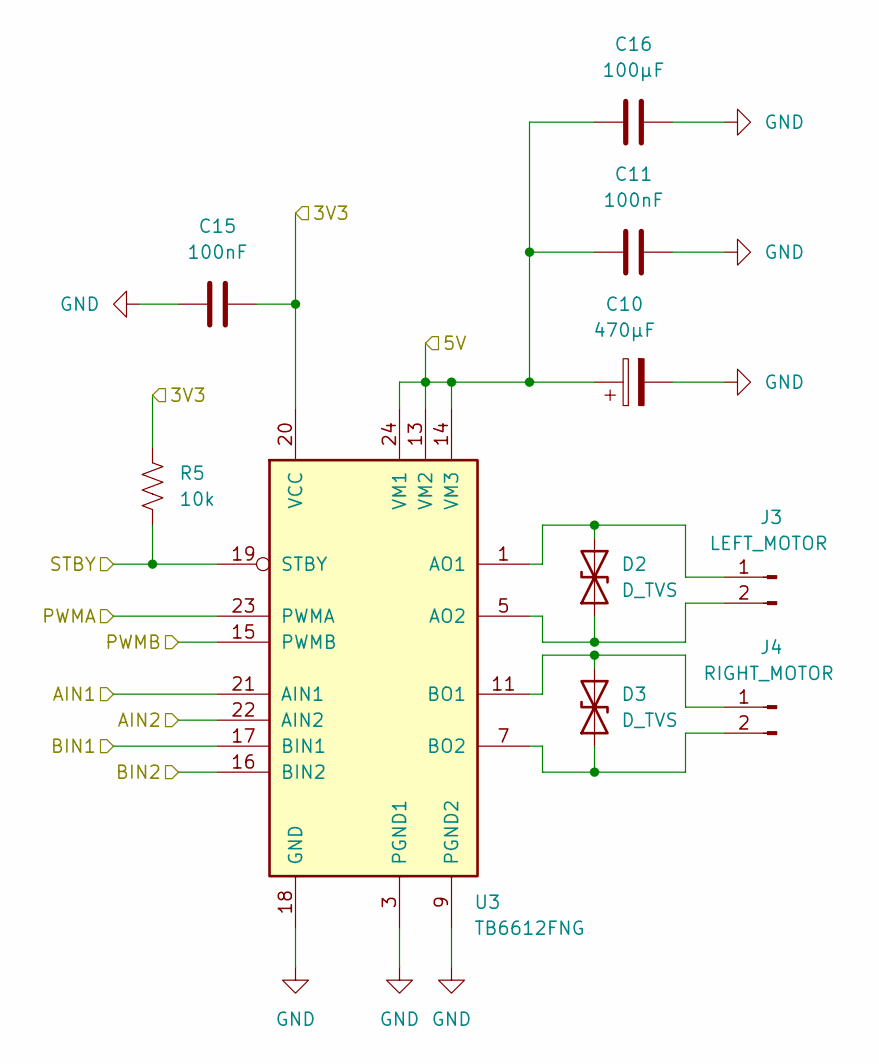
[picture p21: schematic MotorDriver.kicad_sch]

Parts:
C10: 470μF; C_Elec_6.3x5.8
C11, C15: 100nF; C_0805_2012Metric
C16: 100μF; C_1206_3216Metric
D2, D3: D_TVS; D_SMA
J3: LEFT_MOTOR; JST_VH_B2P-VH_1x02_P3.96mm_Vertical
J4: RIGHT_MOTOR; JST_VH_B2P-VH_1x02_P3.96mm_Vertical
R5: 10k; R_0805_2012Metric
U3: TB6612FNG; HTSSOP-24-1EP_4.4x7.8mm_P0.65mm_EP3.4x7.8mm_Mask2.4x4.68mm

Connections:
/Debug/3V3: C15.2, R5.1, U3.20 (VCC); also elsewhere on the board
/Motor Driver/5V: C10.1, C11.1, C16.1, U3.13 (VM2), U3.14 (VM3), U3.24 (VM1); also elsewhere on the board
/Motor Driver/AIN1: U3.21 (AIN1); also elsewhere on the board
/Motor Driver/AIN2: U3.22 (AIN2); also elsewhere on the board
/Motor Driver/BIN1: U3.17 (BIN1); also elsewhere on the board
/Motor Driver/BIN2: U3.16 (BIN2); also elsewhere on the board
/Motor Driver/PWMA: U3.23 (PWMA); also elsewhere on the board
/Motor Driver/PWMB: U3.15 (PWMB); also elsewhere on the board
/Motor Driver/STBY: R5.2, U3.19 (STBY); also elsewhere on the board
GND: C10.2, C11.2, C15.1, C16.2, U3.3 (PGND1), U3.4 (PGND1), U3.9 (PGND2), U3.10 (PGND2), U3.18 (GND); also elsewhere on the board
unnamed: D2.1 (A1), J3.2, U3.5 (AO2), U3.6 (AO2)
unnamed: D2.2 (A2), J3.1, U3.1 (AO1), U3.2 (AO1)
unnamed: D3.1 (A1), J4.2, U3.7 (BO2), U3.8 (BO2)
unnamed: D3.2 (A2), J4.1, U3.11 (BO1), U3.12 (BO1)

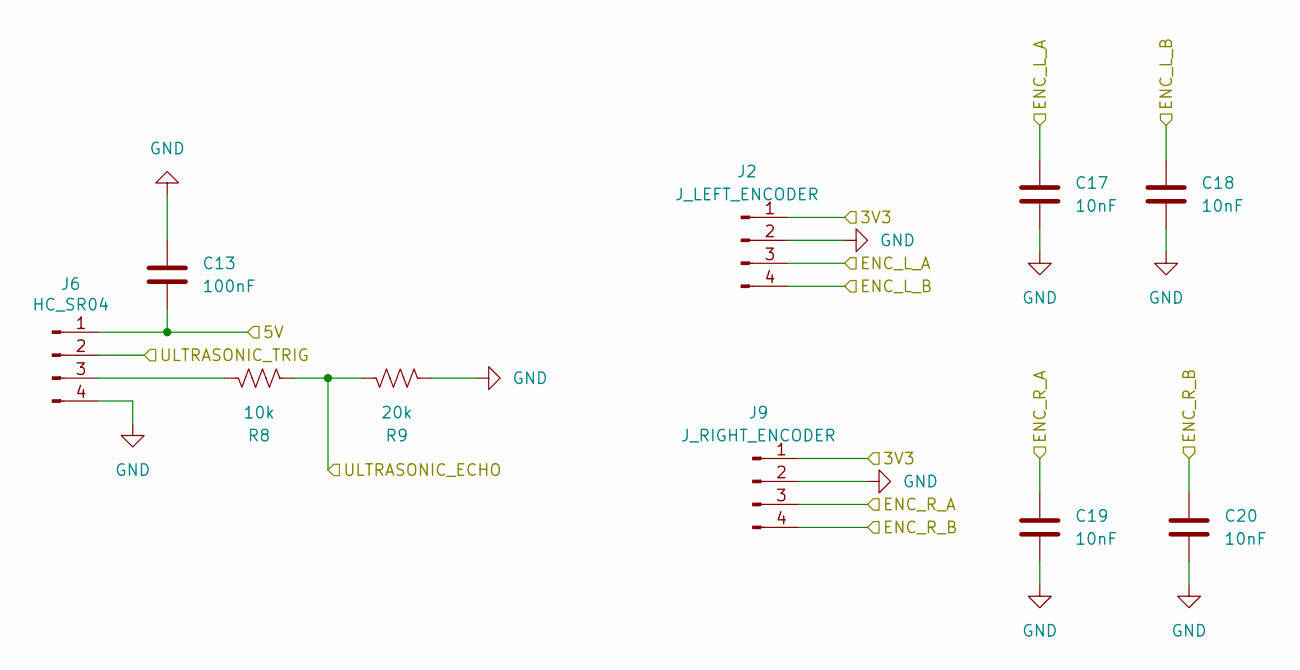
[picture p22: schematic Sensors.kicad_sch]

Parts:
C13: 100nF; C_0805_2012Metric
C17, C18, C19, C20: 10nF; C_0805_2012Metric
J2: J_LEFT_ENCODER; PinHeader_1x04_P2.54mm_Vertical
J6: HC_SR04; PinHeader_1x04_P2.54mm_Vertical
J9: J_RIGHT_ENCODER; PinHeader_1x04_P2.54mm_Vertical
R8: 10k; R_0805_2012Metric
R9: 20k; R_0805_2012Metric

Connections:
/Debug/3V3: J2.1, J9.1; also elsewhere on the board
/Motor Driver/5V: C13.2, J6.1; also elsewhere on the board
/STM32/ENC_L_A: C17.1, J2.3; also elsewhere on the board
/STM32/ENC_L_B: C18.1, J2.4; also elsewhere on the board
/STM32/ENC_R_A: C19.1, J9.3; also elsewhere on the board
/STM32/ENC_R_B: C20.1, J9.4; also elsewhere on the board
/STM32/ULTRASONIC_ECHO: R8.2, R9.1; also elsewhere on the board
/STM32/ULTRASONIC_TRIG: J6.2; also elsewhere on the board
GND: C13.1, C17.2, C18.2, C19.2, C20.2, J2.2, J6.4, J9.2, R9.2; also elsewhere on the board
unnamed: J6.3, R8.1

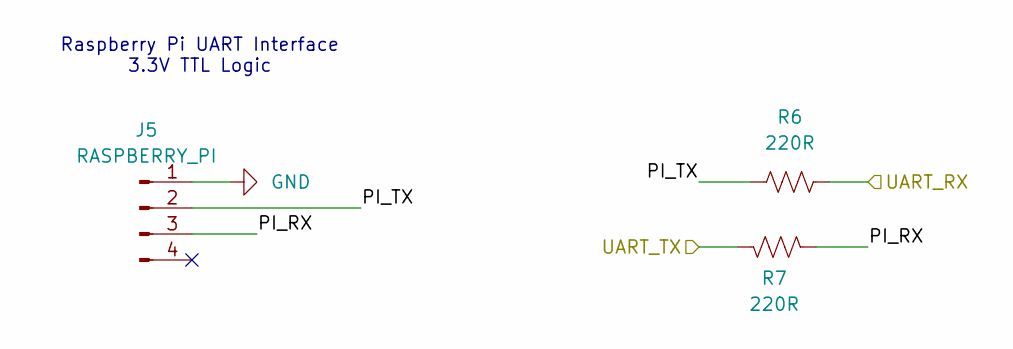
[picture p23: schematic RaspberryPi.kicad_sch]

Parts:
J5: RASPBERRY_PI; PinHeader_1x04_P2.54mm_Vertical
R6, R7: 220R; R_0805_2012Metric

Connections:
/Raspberry Pi/PI_RX: J5.3, R7.2
/Raspberry Pi/PI_TX: J5.2, R6.1
/Raspberry Pi/UART_RX: R6.2; also elsewhere on the board
/Raspberry Pi/UART_TX: R7.1; also elsewhere on the board
GND: J5.1; also elsewhere on the board

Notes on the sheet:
Raspberry Pi UART Interface 3.3V TTL Logic

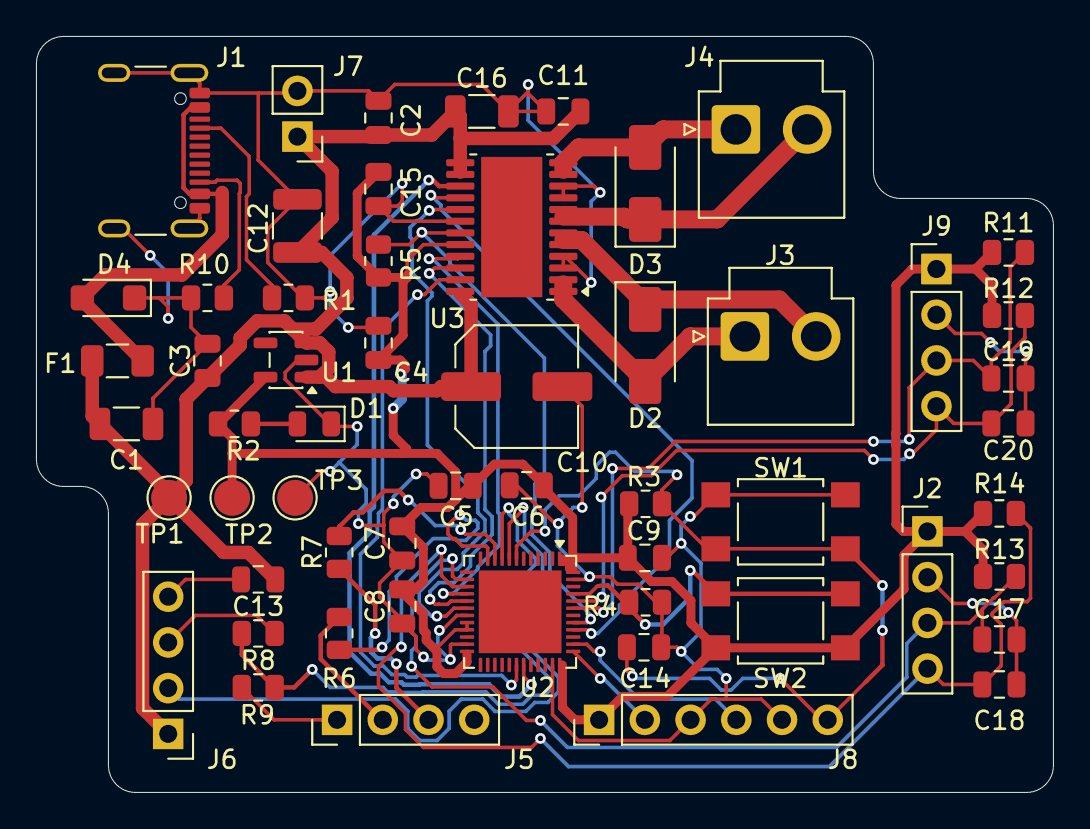
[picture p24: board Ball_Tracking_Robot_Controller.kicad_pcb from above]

Board: 2 copper layers, 56.5 x 42.0 mm, 56 parts (0 on the bottom side), 33 nets.

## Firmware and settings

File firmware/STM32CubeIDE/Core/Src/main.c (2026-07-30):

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
/* Includes ------------------------------------------------------------------*/
#include "main.h"

/* USER CODE BEGIN Includes */
#include "motor.h"
#include "encoder.h"
#include "pid.h"
#include "uart_control.h"
#include "ultrasonic.h"
/* USER CODE END Includes */

/* USER CODE BEGIN PD */
#define CONTROL_LOOP_PERIOD_MS   20   // 50Hz
#define ULTRASONIC_PERIOD_MS     100  // 10Hz, blocking read
/* USER CODE END PD */

TIM_HandleTypeDef htim1;
TIM_HandleTypeDef htim3;
TIM_HandleTypeDef htim4;

UART_HandleTypeDef huart2;

/* USER CODE BEGIN PV */
PID_t left_pid;
PID_t right_pid;

float target_left = 0;
float target_right = 0;

uint32_t last_control_time = 0;
/* USER CODE END PV */

void SystemClock_Config(void);
static void MX_GPIO_Init(void);
static void MX_USART2_UART_Init(void);
static void MX_TIM1_Init(void);
static void MX_TIM3_Init(void);
static void MX_TIM4_Init(void);
/**
  * @brief  The application entry point.
  * @retval int
  */
int main(void)
{

  /* MCU Configuration--------------------------------------------------------*/

  /* Reset of all peripherals, Initializes the Flash interface and the Systick. */
  HAL_Init();

  /* Configure the system clock */
  SystemClock_Config();

  /* Initialize all configured peripherals */
  MX_GPIO_Init();
  MX_USART2_UART_Init();
  MX_TIM1_Init();
  MX_TIM3_Init();
  MX_TIM4_Init();
  /* USER CODE BEGIN 2 */

  HAL_TIM_PWM_Start(&htim1, TIM_CHANNEL_1);
  HAL_TIM_PWM_Start(&htim1, TIM_CHANNEL_2);

  HAL_TIM_Encoder_Start(&htim3, TIM_CHANNEL_ALL);
  HAL_TIM_Encoder_Start(&htim4, TIM_CHANNEL_ALL);

  HAL_GPIO_WritePin(GPIOB, STBY_Pin, GPIO_PIN_SET);  // enable motor driver

  // gains are a starting point, tune on real hardware
  PID_Init(&left_pid, 2.0, 0.1, 0.01);
  PID_Init(&right_pid, 2.0, 0.1, 0.01);

  UART_Init();
  Ultrasonic_Init();

  last_control_time = HAL_GetTick();
  uint32_t last_ultrasonic_time = HAL_GetTick();

  /* USER CODE END 2 */

  /* Infinite loop */
  /* USER CODE BEGIN WHILE */
  while (1)
  {
    uint32_t now = HAL_GetTick();

    if ((now - last_control_time) >= CONTROL_LOOP_PERIOD_MS)
    {
      float dt = (now - last_control_time) / 1000.0f;
      last_control_time = now;

      Encoder_Update(dt);

      float left_output = PID_Update(&left_pid, target_left,
                                      Encoder_GetLeftSpeed(), dt);
      float right_output = PID_Update(&right_pid, target_right,
                                       Encoder_GetRightSpeed(), dt);

      Motor_Left((int16_t)left_output);
      Motor_Right((int16_t)right_output);

      UART_Update();
    }

    // ultrasonic runs slower than the control loop since it's a blocking read
    if ((now - last_ultrasonic_time) >= ULTRASONIC_PERIOD_MS)
    {
      last_ultrasonic_time = now;
      Ultrasonic_Update();
    }

    /* USER CODE END WHILE */

    /* USER CODE BEGIN 3 */
  }
  /* USER CODE END 3 */
}

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


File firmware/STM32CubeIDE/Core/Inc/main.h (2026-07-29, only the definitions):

#define ULTRASONIC_TRIG_Pin GPIO_PIN_0
#define ULTRASONIC_TRIG_GPIO_Port GPIOA
#define ULTRASONIC_ECHO_Pin GPIO_PIN_1
#define ULTRASONIC_ECHO_GPIO_Port GPIOA
#define PI_TX_Pin GPIO_PIN_2
#define PI_TX_GPIO_Port GPIOA
#define PI_RX_Pin GPIO_PIN_3
#define PI_RX_GPIO_Port GPIOA
#define AIN1_Pin GPIO_PIN_0
#define AIN1_GPIO_Port GPIOB
#define AIN2_Pin GPIO_PIN_1
#define AIN2_GPIO_Port GPIOB
#define BIN1_Pin GPIO_PIN_2
#define BIN1_GPIO_Port GPIOB
#define BIN2_Pin GPIO_PIN_3
#define BIN2_GPIO_Port GPIOB
#define STBY_Pin GPIO_PIN_4
#define STBY_GPIO_Port GPIOB

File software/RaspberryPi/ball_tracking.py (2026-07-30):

#!/usr/bin/env python3
"""
Red ball tracker -> STM32G431 robot controller over UART.
Commands match uart_control.c: F/B/L/R/S.

Setup:
    raspi-config -> Interface Options -> Serial Port (enable, disable login shell)
    pip install picamera2 opencv-python pyserial numpy

Wiring: Pi TX(GPIO14) -> STM32 PA3, Pi RX(GPIO15) -> STM32 PA2, common GND.
"""

import sys
import time
import threading

import serial
import cv2
import numpy as np
from picamera2 import Picamera2

SERIAL_PORT = "/dev/serial0"
SERIAL_BAUD = 115200

FRAME_WIDTH = 640
FRAME_HEIGHT = 480

# red wraps hue 0/180, so two ranges
LOWER_RED_1 = np.array([0, 120, 70])
UPPER_RED_1 = np.array([10, 255, 255])
LOWER_RED_2 = np.array([170, 120, 70])
UPPER_RED_2 = np.array([180, 255, 255])

MIN_BALL_RADIUS_PX = 8
CENTER_DEADZONE_PX = 40

RADIUS_TOO_FAR_PX = 30
RADIUS_TOO_CLOSE_PX = 70

COMMAND_RESEND_PERIOD_S = 0.15   # stay under the STM32's 500ms watchdog
NO_BALL_STOP_TIMEOUT_S = 1.0

SHOW_DEBUG_WINDOW = False


class SerialCommander:
    """Resends the current command on its own thread so the STM32's
    UART watchdog never trips due to camera frame time."""

    def __init__(self, port, baud, resend_period_s):
        self._ser = serial.Serial(port, baud, timeout=0.1)
        self._resend_period_s = resend_period_s
        self._lock = threading.Lock()
        self._command = 'S'
        self._stop_event = threading.Event()
        self._thread = threading.Thread(target=self._run, daemon=True)
        self._thread.start()

    def set_command(self, command):
        with self._lock:
            self._command = command

    def _run(self):
        while not self._stop_event.is_set():
            with self._lock:
                command = self._command
            try:
                self._ser.write(command.encode('ascii'))
            except serial.SerialException as exc:
                print(f"Serial write failed: {exc}", file=sys.stderr)
            time.sleep(self._resend_period_s)

    def close(self):
        self._stop_event.set()
        self._thread.join(timeout=1.0)
        try:
            self._ser.write(b'S')
            time.sleep(0.05)
        except serial.SerialException:
            pass
        self._ser.close()


class BallTracker:
    def __init__(self):
        self.picam2 = Picamera2()
        config = self.picam2.create_preview_configuration(
            main={"format": "RGB888", "size": (FRAME_WIDTH, FRAME_HEIGHT)}
        )
        self.picam2.configure(config)
        self.picam2.start()
        time.sleep(1.0)  # let AE/AWB settle

    def find_ball(self, frame_bgr):
        """Return (cx, cy, radius) of the largest red blob, or None."""
        hsv = cv2.cvtColor(frame_bgr, cv2.COLOR_BGR2HSV)
        mask1 = cv2.inRange(hsv, LOWER_RED_1, UPPER_RED_1)
        mask2 = cv2.inRange(hsv, LOWER_RED_2, UPPER_RED_2)
        mask = cv2.bitwise_or(mask1, mask2)
        mask = cv2.erode(mask, None, iterations=2)
        mask = cv2.dilate(mask, None, iterations=2)

        contours, _ = cv2.findContours(mask, cv2.RETR_EXTERNAL, cv2.CHAIN_APPROX_SIMPLE)
        if not contours:
            return None

        largest = max(contours, key=cv2.contourArea)
        (x, y), radius = cv2.minEnclosingCircle(largest)
        if radius < MIN_BALL_RADIUS_PX:
            return None

        return (int(x), int(y), int(radius))

    def capture_frame(self):
        rgb = self.picam2.capture_array()
        return cv2.cvtColor(rgb, cv2.COLOR_RGB2BGR)

    def close(self):
        self.picam2.stop()


def decide_command(ball, frame_width):
    if ball is None:
        return None

    cx, _cy, radius = ball
    offset_x = cx - frame_width // 2

    if offset_x < -CENTER_DEADZONE_PX:
        return 'L'
    if offset_x > CENTER_DEADZONE_PX:
        return 'R'
    if radius < RADIUS_TOO_FAR_PX:
        return 'F'
    if radius > RADIUS_TOO_CLOSE_PX:
        return 'B'
    return 'S'


def main():
    try:
        commander = SerialCommander(SERIAL_PORT, SERIAL_BAUD, COMMAND_RESEND_PERIOD_S)
    except serial.SerialException as exc:
        print(f"Failed to open serial port {SERIAL_PORT}: {exc}", file=sys.stderr)
        return 1

    try:
        tracker = BallTracker()
    except Exception as exc:
        print(f"Failed to start camera: {exc}", file=sys.stderr)
        commander.close()
        return 1

    last_command = 'S'
    last_seen_time = time.monotonic()

    print("Red ball tracker running. Ctrl+C to stop.")

    try:
        while True:
            frame = tracker.capture_frame()
            ball = tracker.find_ball(frame)
            now = time.monotonic()

            if ball is not None:
                last_seen_time = now
                command = decide_command(ball, FRAME_WIDTH)
            elif (now - last_seen_time) > NO_BALL_STOP_TIMEOUT_S:
                command = 'S'
            else:
                command = last_command

            if command != last_command:
                print(f"-> {command}")
            last_command = command
            commander.set_command(command)

            if SHOW_DEBUG_WINDOW:
                if ball is not None:
                    cx, cy, radius = ball
                    cv2.circle(frame, (cx, cy), radius, (0, 255, 0), 2)
                    cv2.circle(frame, (cx, cy), 3, (0, 0, 255), -1)
                cv2.putText(frame, f"cmd: {last_command}", (10, 30),
                            cv2.FONT_HERSHEY_SIMPLEX, 1, (255, 255, 255), 2)
                cv2.imshow("Tracker", frame)
                if cv2.waitKey(1) & 0xFF == ord('q'):
                    break

    except KeyboardInterrupt:
        print("\nStopping.")
    finally:
        commander.set_command('S')
        time.sleep(COMMAND_RESEND_PERIOD_S * 2)
        commander.close()
        tracker.close()
        if SHOW_DEBUG_WINDOW:
            cv2.destroyAllWindows()

    return 0


if __name__ == "__main__":
    sys.exit(main())

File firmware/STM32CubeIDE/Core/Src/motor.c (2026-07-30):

#include "motor.h"

extern TIM_HandleTypeDef htim1;

void Motor_Left(int16_t pwm)
{
  if (pwm > 1000) pwm = 1000;
  if (pwm < -1000) pwm = -1000;

  if (pwm >= 0)
  {
    HAL_GPIO_WritePin(GPIOB, AIN1_Pin, GPIO_PIN_SET);
    HAL_GPIO_WritePin(GPIOB, AIN2_Pin, GPIO_PIN_RESET);
  }
  else
  {
    HAL_GPIO_WritePin(GPIOB, AIN1_Pin, GPIO_PIN_RESET);
    HAL_GPIO_WritePin(GPIOB, AIN2_Pin, GPIO_PIN_SET);
    pwm = -pwm;
  }

  __HAL_TIM_SET_COMPARE(&htim1, TIM_CHANNEL_1, pwm * 65);
}

void Motor_Right(int16_t pwm)
{
  if (pwm > 1000) pwm = 1000;
  if (pwm < -1000) pwm = -1000;

  if (pwm >= 0)
  {
    HAL_GPIO_WritePin(GPIOB, BIN1_Pin, GPIO_PIN_SET);
    HAL_GPIO_WritePin(GPIOB, BIN2_Pin, GPIO_PIN_RESET);
  }
  else
  {
    HAL_GPIO_WritePin(GPIOB, BIN1_Pin, GPIO_PIN_RESET);
    HAL_GPIO_WritePin(GPIOB, BIN2_Pin, GPIO_PIN_SET);
    pwm = -pwm;
  }

  __HAL_TIM_SET_COMPARE(&htim1, TIM_CHANNEL_2, pwm * 65);
}

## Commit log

2026-07-29 Create pcb
2026-07-29 Add STM32 HAL drivers
2026-07-29 added pcb gerbers and BOM
    [Ball_Tracking_Robot_BOM.csv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]
2026-07-29 kicad schematic files added
    [Debug.kicad_sch, MotorDriver.kicad_sch, Power.kicad_sch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]

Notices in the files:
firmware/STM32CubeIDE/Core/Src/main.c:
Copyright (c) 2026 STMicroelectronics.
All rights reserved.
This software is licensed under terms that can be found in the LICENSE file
